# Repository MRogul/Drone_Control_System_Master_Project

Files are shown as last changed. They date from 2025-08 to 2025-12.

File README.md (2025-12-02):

# 🚀 Drone Control System – Master Project

**Test stand for evaluating drone control systems with 4DOF**  
_Master’s Thesis Project by [Michał Rogulski](https://github.com/MRogul)_

---

## 📘 Project Summary

This repository contains the full implementation of a 4-DOF quadrotor control system, including:

• custom-built experimental test stand,

• STM32 firmware for sensor acquisition, control algorithms and motor mixing,

• ESP8266-based web interface for real-time tuning,

• MATLAB/Simulink models used for controller prototyping and simulation,

• a complete validation pipeline comparing the mathematical model with real measurements.

The project was developed as part of a Master’s Thesis in Control Engineering.
---

## 📸 Real Test Stand

| Final Stand | Initial Concept |
|:---:|:---:|
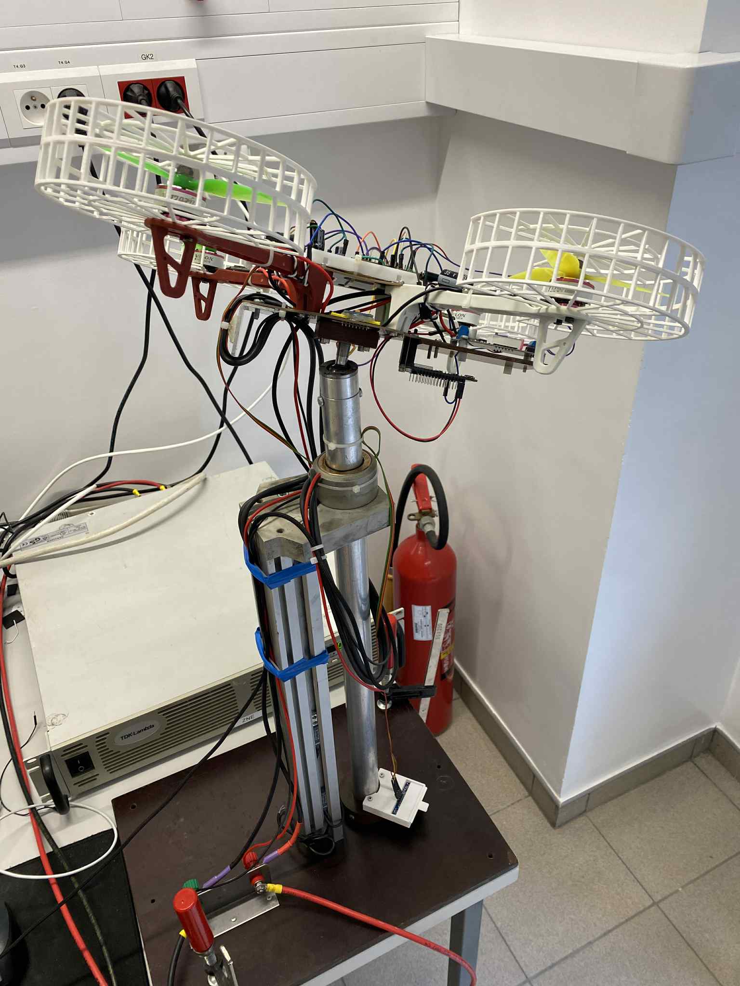
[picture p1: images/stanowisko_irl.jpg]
4DOF Stand
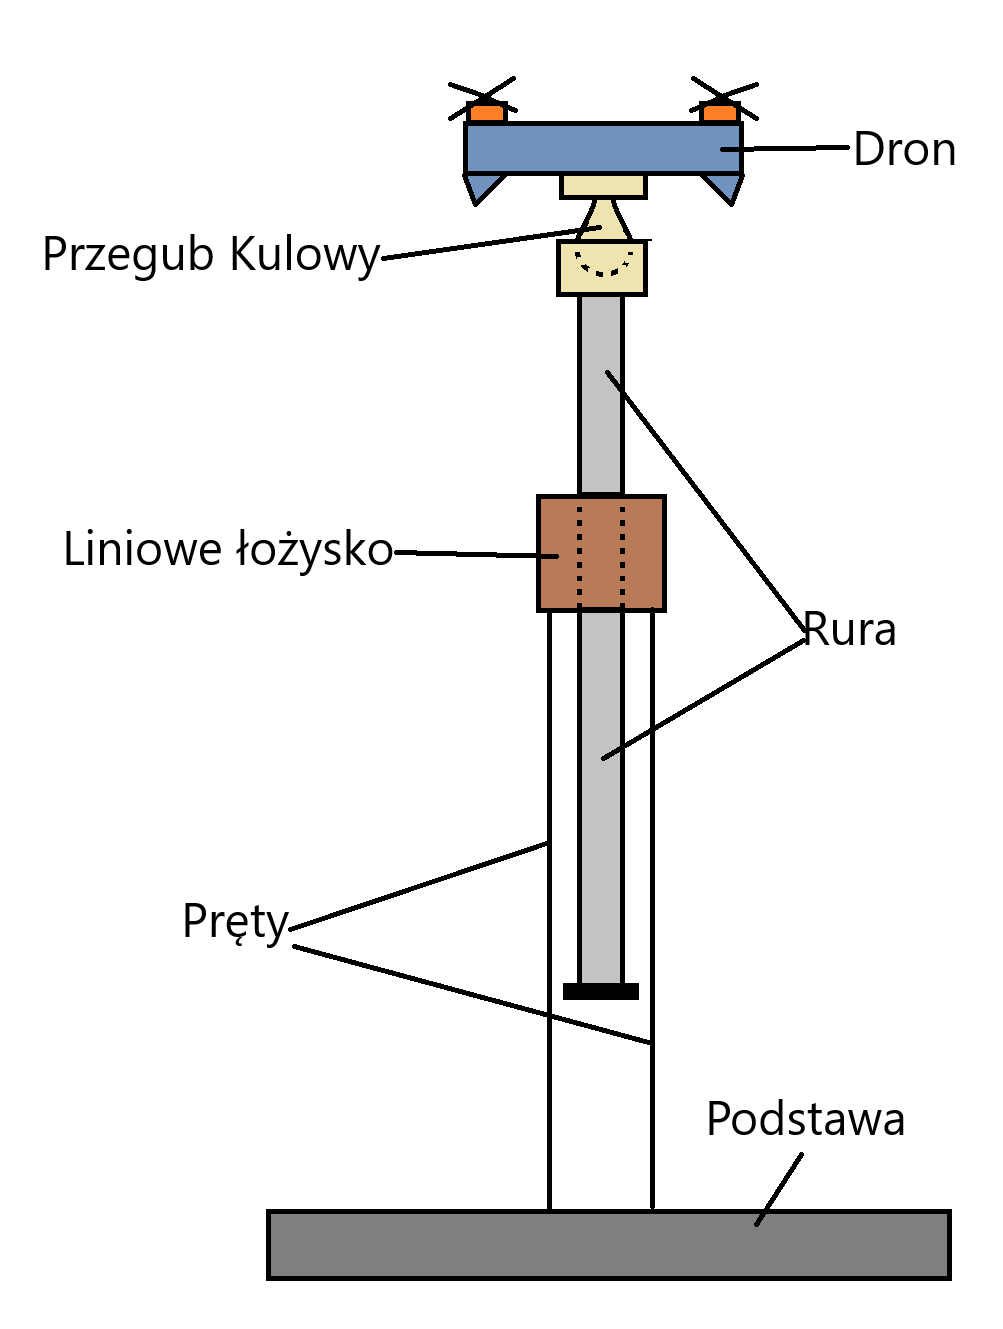
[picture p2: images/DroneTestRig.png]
Concept
|  |  |
| **4DOF Research Stand (Final version)** | **Initial design of the test rig** |

---

## ⚙️ Project Highlights

✨ **Embedded Control System (STM32)**

• Four PID loops: roll, pitch, yaw, altitude (Z)

• Derivative-on-measurement (reduces derivative kick)

• Anti-windup (conditional integration)

• Mixer for quadcopter X-configuration

• Digital ESC control via DShot300

🧠 **Sensor Fusion Algorithms**

• Complementary filter (custom implementation)

• Kalman filter (custom implementation)

• BNO055 onboard fusion (BSX) as reference

🌐 **Real-Time Tuning via ESP8266**

• Web UI hosted directly on ESP8266 (AP mode)

• Live PID tuning

• Real-time telemetry

• No need to reflash STM32 to change parameters

🛠️ **Simulation & Validation**

• 4DOF Simulink model (Plant + Sensors + Mixer + PID)

• Comparison against real test stand

• Step-response evaluation for all controlled axes

• Analysis of estimator influence on closed-loop behaviour

---

## 🗂 Repository Structure

Drone_Control_System_Master_Project/

│

├── Drone_Control/          # STM32 code (IMU, sonar, PID, mixer, DShot)

├── ESP8266/                # Web interface for real-time tuning

├── MATLAB/                 # 4DOF simulation model

├── CAD files/              # CAD files of the test stand

├── Library/BNO055/         # BNO055 Library

├── images/                 # Photos and diagrams

├── Datasheets/             # Helpful materials

├── Results/                # Responses and comparisons

└── README.md

---

## 🧠 Technologies Used

| Category | Tools |
|---|---|
| Microcontroller | STM32L432KC |
| IDE | STM32CubeMX |
| Communication | ESP8266 (Wi-Fi, Web Interface) |
| Simulation | MATLAB / Simulink |
| Visualization | STM32CubeMonitor |
| Mechanical Design | Fusion 360 / Bambu Studio |

---

## 🧪 Experimental Results

Tests performed on the 4DOF stand include:

• step responses for roll, pitch, yaw and vertical altitude (Z)

• comparison of Complementary, Kalman and BNO055 fusion

• PID tuning experiments in simulation and on hardware

• validation of control structure and estimator performance

All implemented algorithms (PID + sensor fusion) behave correctly and consistently across simulation and physical testing.

---

## 🪶 About the Project

This platform demonstrates how a complete UAV stabilization system can be built using accessible components, providing:

• safe indoor flight testing,

• repeatable laboratory experiments,

• a foundation for research on estimation & control,

• a practical educational tool for UAV control engineering.

---

## 📄 License

This project is licensed under the **MIT License**.  
You are free to use and modify it for academic or research purposes.

---

**Author:** [Michał Rogulski](https://github.com/MRogul)  
🎓 Warsaw University of Technology  
📘 [Drone_Control_System_Master_Project](https://github.com/MRogul/Drone_Control_System_Master_Project)

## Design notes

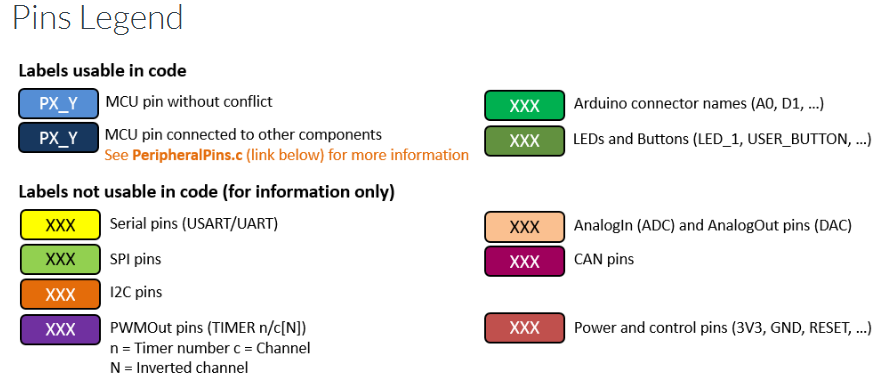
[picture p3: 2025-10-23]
Datasheets/STM32/Pinout-legend.png

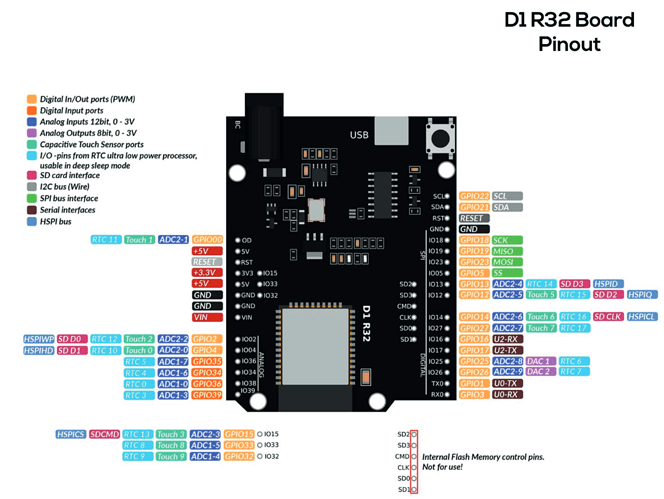
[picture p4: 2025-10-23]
Datasheets/D1 esp32 Pinout.png

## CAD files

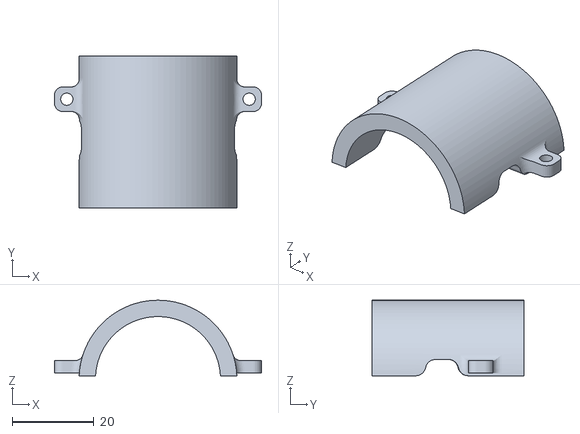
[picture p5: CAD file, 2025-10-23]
CAD files/1DOF do Drone 2 part.stl
50.5 x 37.0 x 18.4

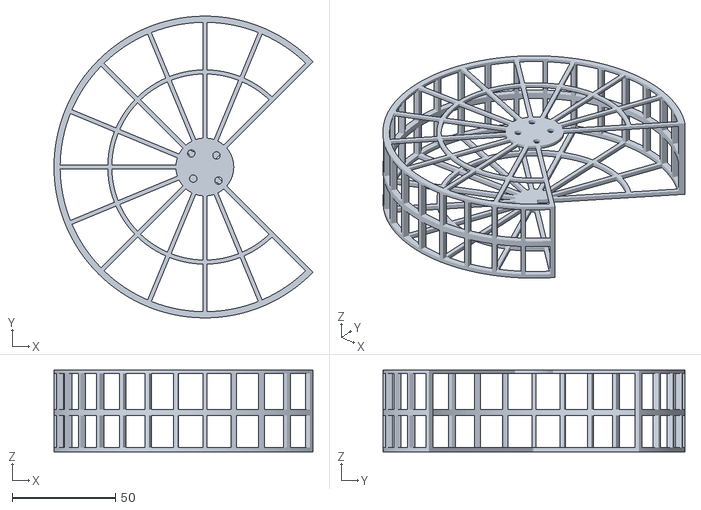
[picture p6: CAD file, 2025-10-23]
CAD files/MotorCase.stl
125.3 x 146.0 x 39.5

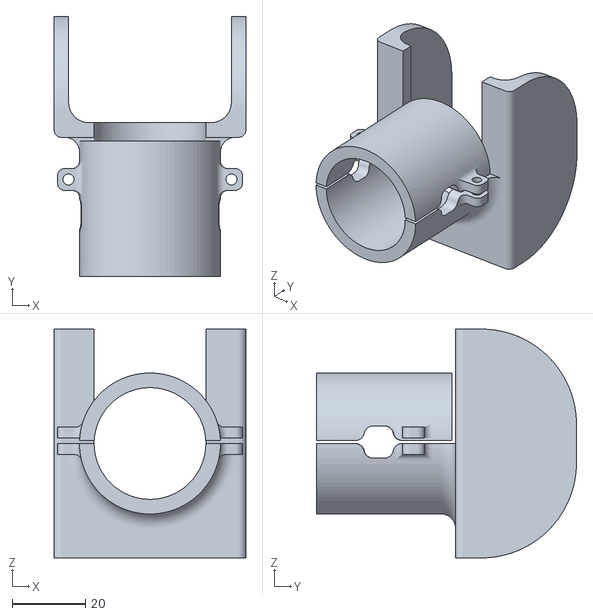
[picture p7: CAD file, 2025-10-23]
CAD files/1DOF to Drone.stl
52.4 x 71.0 x 62.5

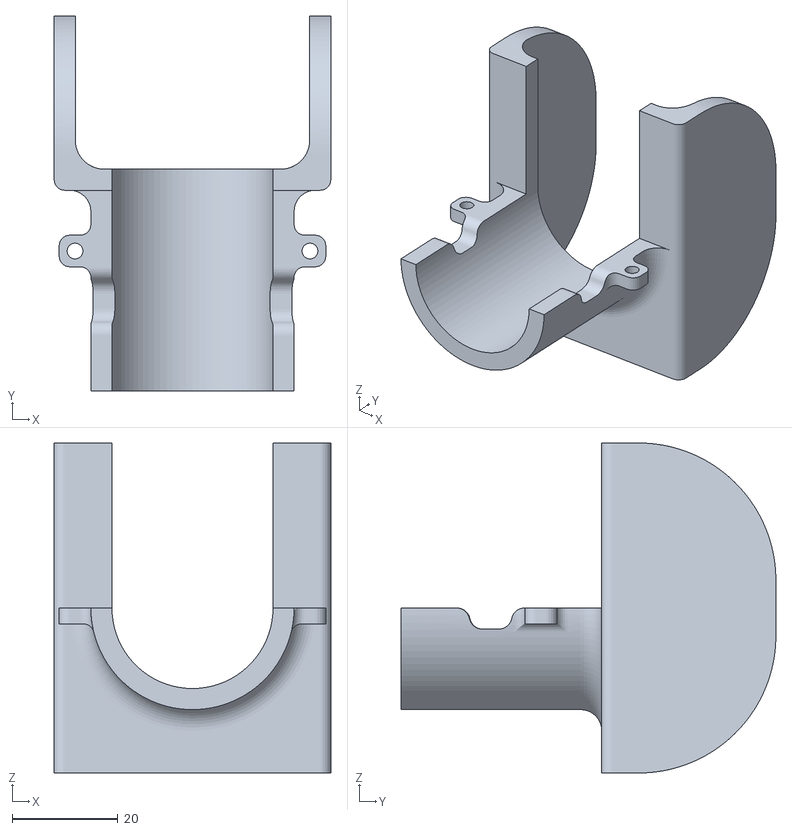
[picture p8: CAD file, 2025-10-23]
CAD files/1DOF do Drone 1part.stl
52.4 x 71.0 x 62.5

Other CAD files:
CAD files/1DOF do Drone 1part.f3d
CAD files/1DOF do Drone 2part.f3d
CAD files/1DOF do Drone.f3d
CAD files/MotorCase.f3d

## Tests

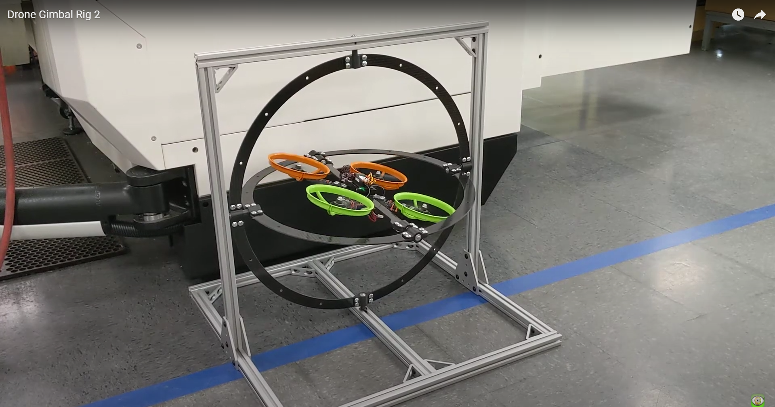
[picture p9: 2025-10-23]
images/Test rigs/3DOF-MINDS.png

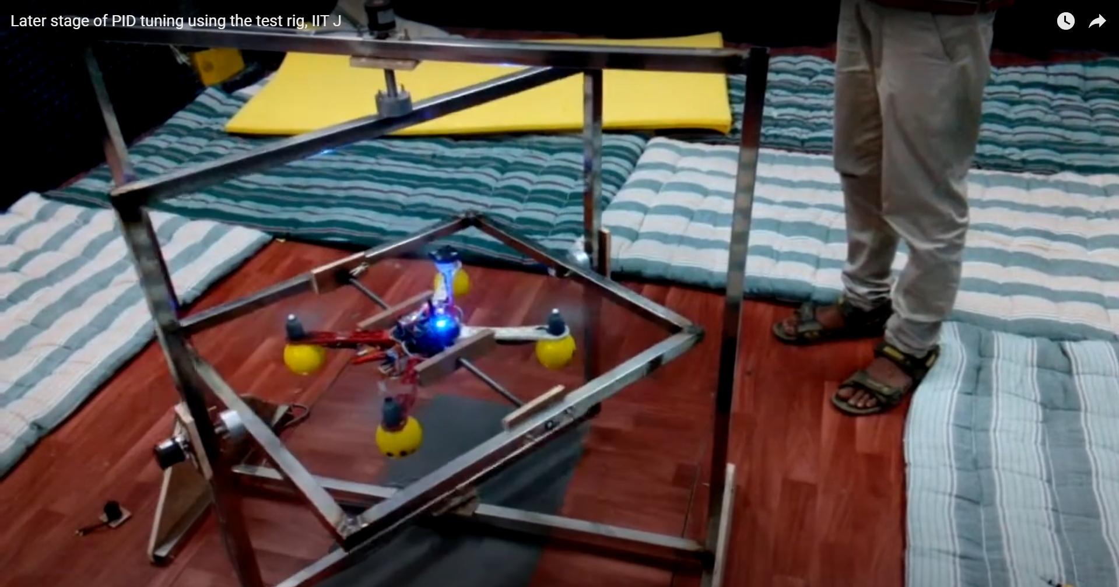
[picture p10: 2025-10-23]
images/Test rigs/3DOF-Durge.png

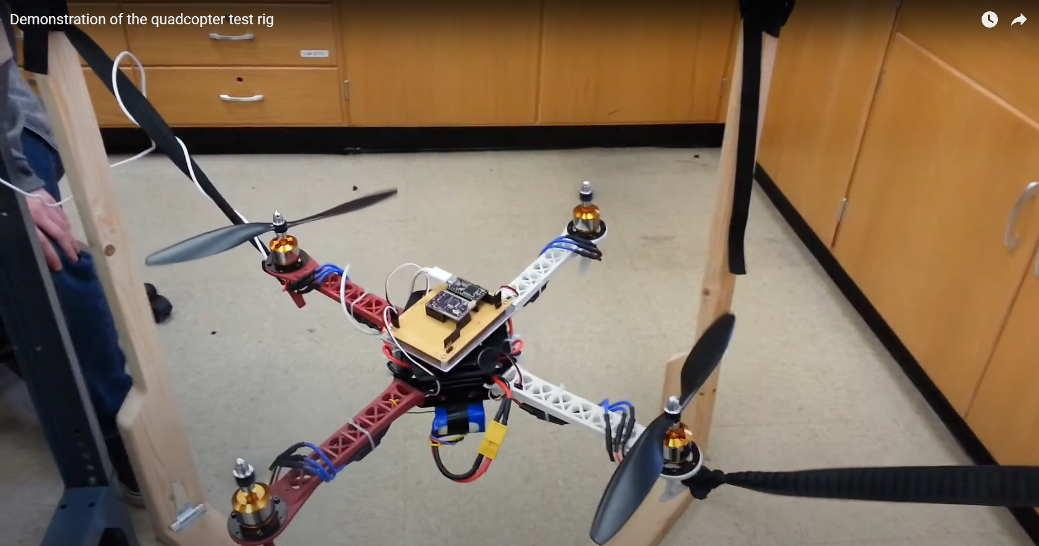
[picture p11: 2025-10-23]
images/Test rigs/DoaUAV - 1dof.png

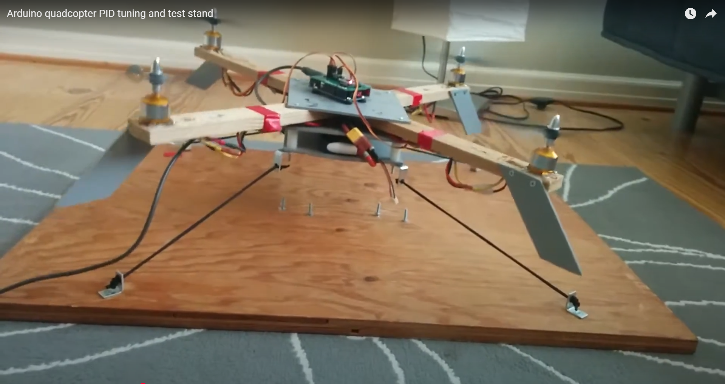
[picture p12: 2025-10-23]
images/Test rigs/2DOF-Amir.png

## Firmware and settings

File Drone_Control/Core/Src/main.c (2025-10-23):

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
/* Includes ------------------------------------------------------------------*/
#include <imu_complementary_filter.h>
#include "main.h"
#include "crc.h"
#include "dma.h"
#include "i2c.h"
#include "tim.h"
#include "usart.h"
#include "gpio.h"

/* USER CODE BEGIN Includes */
#include "dshot300.h"
#include "mpu6050.h"
#include "stdio.h"//printf function
#include "pid_controller.h"
#include <string.h>
#include <stdbool.h>
#include "bno055_stm32.h"
#include "imu_kalman_filter.h"
#include "imu_complementary_filter.h"
#include "esp32_cmd.h"
#include "hcsr04.h"

/* USER CODE END Includes */

/* USER CODE BEGIN PD */
#define ESP32_UART_HANDLE &huart2
#define ESP32_MSG_LENGTH 6
#define BNO_I2C_HANDLE &hi2c3

#define SAMPLE_TIME 0.01f

#define PID_KP_MIN 4.0f
#define PID_KP_MAX 12.0f
#define PID_KI_MIN 0.1f
#define PID_KI_MAX 5.0f
#define PID_KD_MIN 4.0f
#define PID_KD_MAX 20.0f
#define PID_TAU_MIN 0.1f
#define PID_TAU_MAX 0.2f

#define ROLL_REF_MIN -15.0f
#define ROLL_REF_MAX 15.0f

#define PITCH_REF_MIN -15.0f
#define PITCH_REF_MAX 15.0f

#define YAW_REF_MIN 100.0f
#define YAW_REF_MAX 200.0f

#define Z_REF_MIN 3.0f
#define Z_REF_MAX 20.0f

#define YAW_BIAS 150.0f

#define SPEED_MIN 48
#define MAX_SPEED 1900

#define SPEED_OFFSET 600.0f
#define ADC_TIMEOUT 1   // us

#define speed 200

//Kalman filter parameters

#define Qa_roll  0.006955685f
#define Qa_pitch  0.012531481f

#define Qb_roll  0.00006955685f
#define Qb_pitch  0.00006955685f

#define R_roll 0.00708008f
#define R_pitch 0.005146486f

/* USER CODE END PD */


/* USER CODE BEGIN PV */

/* Podstawowe dane i parametry */
uint16_t speed_ref[DSHOT_NUM_MOTORS] = {speed, speed, speed, speed};
volatile uint8_t white_button_flag = 0;

/* PID controllery */
PID_t pid_pitch;
PID_t pid_roll;
PID_t pid_yaw;
PID_t pid_z;

/* Wzmocnienia regulatorów */
float kp = 4.5f;
float ki = 2.6f;
float kd = 14.0f;
float tau = 0.09f;

float kp_y = 5.0f;
float ki_y = 1.5f;
float kd_y = 12.0f;
float tau_y = 0.1f;

float kp_z = 22.0f;
float ki_z = 6.0f;
float kd_z = 8.0f;
float tau_z = 0.1f;

/* Liczniki i sygnały odniesienia */
volatile float pid_z_counter = 1.0f;
volatile float ref_signal_counter = -1000.0f;
volatile uint8_t num_ref = 0;
volatile uint8_t num_ref_prev = 0;

/* Wartości zadane */
float REF_PITCH_ANGLE = 0.0f;
float REF_ROLL_ANGLE  = 0.0f;
float REF_YAW_ANGLE   = 100.0f;
float REF_Z_DISTANCE  = 10.0f;

/* Sekwencje sygnałów odniesienia */
static const float ref_signals[][4] = {
    // pitch, roll, yaw, z
    [0]  = {0.0, 0.0, 100.0, 10.0},
    [1]  = {0.0, 0.0, 100.0, 20.0},
    [2]  = {0.0, 0.0, 100.0, 10.0},
    [3]  = {0.0, 0.0, 200.0, 10.0},
    [4]  = {0.0, 0.0, 100.0, 10.0},
    [5]  = {10.0, 0.0, 100.0, 10.0},
    [6]  = {-10.0, 0.0, 100.0, 10.0},
    [7]  = {0.0, 10.0, 100.0, 10.0},
    [8]  = {0.0, -10.0, 100.0, 10.0},
    [9]  = {0.0, 0.0, 100.0, 10.0},
    [10] = {0.0, 0.0, 100.0, 3.0},
    [11] = {0.0, 0.0, 100.0, 10.0},
};

/* Flagi i stany systemowe */
volatile uint8_t SS = 0;
volatile uint8_t emergency_stop_flag = 0;

/* Dane z czujników i filtru */
volatile bno055_vector_t bno_vector;
volatile float copter_pitch_angle;
volatile float copter_roll_angle;
volatile float copter_yaw_angle;
volatile float copter_z_distance;

volatile float copter_pitch_angle_kal;
volatile float copter_roll_angle_kal;

/* Wyjścia regulatorów */
volatile float speed_pitch_ref;
volatile float speed_roll_ref;
volatile float speed_yaw_ref;
volatile float speed_z_ref;

/* Sygnały prędkości dla ESC */
volatile uint16_t speed_1_ref;
volatile uint16_t speed_2_ref;
volatile uint16_t speed_3_ref;
volatile uint16_t speed_4_ref;

/* Komunikacja z ESP32 */
uint8_t esp32_data_received_flag = 0;
uint8_t rx_esp32_data[ESP32_MSG_LENGTH];

/* Debug UART */
uint8_t uart_line[64];
int uart_line_length;
uint32_t UartDebugSoftTimer;

/* IMU i filtry */
MPU6050_t MPU6050;
IMU_Angles imu_angles;
KalmanFilter Roll;
KalmanFilter Pitch;

/* HC-SR04 – struktura drivera */
static HCSR04_t hcsr;

/* USER CODE END PV */


void SystemClock_Config(void);
/* USER CODE BEGIN PFP */
uint8_t compute_crc8(const uint8_t *data, uint8_t length);
/* USER CODE END PFP */

/* USER CODE BEGIN 0 */
float AngX, AngY;
/* USER CODE END 0 */

/**
  * @brief  The application entry point.
  * @retval int
  */
int main(void)
{

  /* MCU Configuration--------------------------------------------------------*/

  /* Reset of all peripherals, Initializes the Flash interface and the Systick. */
  HAL_Init();

  /* Configure the system clock */
  SystemClock_Config();

  /* Initialize all configured peripherals */
  MX_GPIO_Init();
  MX_DMA_Init();
  MX_USART2_UART_Init();
  MX_CRC_Init();
  MX_I2C3_Init();
  MX_TIM1_Init();
  MX_USART1_UART_Init();
  MX_TIM2_Init();
  MX_TIM15_Init();
  /* USER CODE BEGIN 2 */
  //MPU6050_Init(&hi2c3);
  //MPU6050_Calibrate_Gyro(&hi2c3, &MPU6050, 500);

  Kalman_Init(&Roll, Qa_roll, Qb_roll, R_roll);
  Kalman_Init(&Pitch, Qa_pitch, Qb_pitch, R_pitch);

  HAL_TIM_Base_Start(&htim2); //Czas do czujników odległościowych
  HAL_TIM_Base_Start_IT(&htim15); //Timer od częstotliwości regulatora i wysyłania prędkości do drona
  //HAL_TIM_Base_Start_IT(&htim1); // control loop interrupt


  // PID controllers
  	PID_Init_Bartek_s_Lab(&pid_pitch, kp, ki, kd,
  	tau, -250.0f, 250.0f, SAMPLE_TIME);

  	PID_Init_Bartek_s_Lab(&pid_roll, kp, ki, kd,
  	tau, -250.0f, 250.0f, SAMPLE_TIME);

  	PID_Init_Bartek_s_Lab(&pid_yaw, kp_y, ki_y, kd_y,
  	tau_y, -300.0f, 300.0f, SAMPLE_TIME);

  	PID_Init_Bartek_s_Lab(&pid_z, kp_z, ki_z, kd_z,
  	  	tau_z, -150.0f, 400.0f, SAMPLE_TIME);

  	UartDebugSoftTimer = HAL_GetTick();

	HAL_Delay(2000); // let the motor stop after uC RST

	dshot_arm_all_esc();

//	SS=2;

	// AHRS
		bno055_assignI2C(BNO_I2C_HANDLE);
		bno055_setup();
		bno055_setOperationModeNDOF();

	static ESP32_CmdCtx esp_ctx = {
		    .pid_pitch = &pid_pitch,
		    .pid_roll  = &pid_roll,
		    .pid_yaw   = &pid_yaw,
		    .pid_z     = &pid_z,

		    .kp = &kp, .ki = &ki, .kd = &kd, .tau = &tau,

		    .kp_y = &kp_y, .ki_y = &ki_y, .kd_y = &kd_y, .tau_y = &tau_y,
		    .kp_z = &kp_z, .ki_z = &ki_z, .kd_z = &kd_z, .tau_z = &tau_z,

		    .ref_roll  = &REF_ROLL_ANGLE,
		    .ref_pitch = &REF_PITCH_ANGLE,
		    .ref_yaw   = &REF_YAW_ANGLE,
		    .ref_z     = &REF_Z_DISTANCE,

		    .kp_min = PID_KP_MIN,   .kp_max = PID_KP_MAX,
		    .ki_min = PID_KI_MIN,   .ki_max = PID_KI_MAX,
		    .kd_min = PID_KD_MIN,   .kd_max = PID_KD_MAX,
		    .tau_min = PID_TAU_MIN, .tau_max = PID_TAU_MAX,

		    .roll_min  = ROLL_REF_MIN,   .roll_max  = ROLL_REF_MAX,
		    .pitch_min = PITCH_REF_MIN,  .pitch_max = PITCH_REF_MAX,
		    .yaw_min   = YAW_REF_MIN,    .yaw_max   = YAW_REF_MAX,
		    .z_min     = Z_REF_MIN,      .z_max     = Z_REF_MAX,
		};

	/* HC-SR04: TIM2 jako licznik czasu ECHO, TRIG/ECHO jak w CubeMX */
	HCSR04_Init(&hcsr,
	            &htim2,
	            1000000u,                  /* timer_hz (tu 1 MHz) */
	            TRIG_PIN_GPIO_Port, TRIG_PIN_Pin,
	            ECHO_PIN_Pin);

	/* Opcjonalnie: co 6 wywołań timera sterującego zrób trigger (jak Twój Trig_counter) */
	HCSR04_SetPeriodicDivider(&hcsr, 6);
	/* Opcjonalnie: długość impulsu TRIG (domyślnie ~50 µs) */
	HCSR04_SetTrigPulse(&hcsr, 400);


  /* USER CODE END 2 */

  /* Infinite loop */
  /* USER CODE BEGIN WHILE */

  	memset(rx_esp32_data, 0x00, ESP32_MSG_LENGTH); //Zeruje bufor rx_esp32_data
  	HAL_UART_Receive_IT(ESP32_UART_HANDLE, rx_esp32_data,ESP32_MSG_LENGTH); // uruchamia odbieranie danych przez UART w trybie przerwań. Kiedy dane przyjdą, zostanie wywołane HAL_UART_RxCpltCallback.
	while (1)
	{

		if (white_button_flag == 1)
		{
			white_button_flag = 0;
			__NOP();
		}
	    (void)ESP32_PollAndProcess(&esp32_data_received_flag,
	                               rx_esp32_data,
	                               ESP32_MSG_LENGTH,    // = 6
	                               &esp_ctx);



//		PID_Controller_Update_Gains(&pid_pitch, kp, ki, kd, tau);
//		PID_Controller_Update_Gains(&pid_roll, kp, ki, kd, tau);
//		PID_Controller_Update_Gains(&pid_yaw, kp_y, ki_y, kd_y, tau_y);
//		PID_Controller_Update_Gains(&pid_z, kp_z, ki_z, kd_z, tau_z);
		if (num_ref!=num_ref_prev){
			REF_SIGNAL(num_ref);
			num_ref_prev=num_ref;
		}

    /* USER CODE END WHILE */

    /* USER CODE BEGIN 3 */
	}
  /* USER CODE END 3 */
}

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
/* USER CODE BEGIN 4 */

//////////////////FUNKCJA ODPOWIADAJĄCA ZA PRZELICZENIE WYCHYLENIA NA PRĘDKOŚCI REFERENCYJNE SILNIKÓW/////////////////////////

void HAL_TIM_PeriodElapsedCallback(TIM_HandleTypeDef *htim) //wejście w przerwanie
{
	uint16_t speeds[4];
	uint16_t base[4];
	//float U_vec[3];

	if (htim->Instance == TIM15) //sprawdzenie od którego timera jest przerwanie
	{
		/* Periodyczne wyzwalanie pomiaru odległości */
		(void)HCSR04_OnPeriodic(&hcsr);

		/* Jeśli przyszła nowa próbka – pobierz i przypisz do zmiennej systemowej */
		if (HCSR04_HasNew(&hcsr)) {
		    copter_z_distance = HCSR04_GetDistanceCm(&hcsr);
		}


		/*
		/////////////POBIERANIE WYCHYLENIA Z CZUJNIKA MPU6050/////////////
		MPU6050_Read_All(&hi2c3, &MPU6050);
		copter_pitch_angle = MPU6050.KalmanAngleX;
		copter_roll_angle = MPU6050.KalmanAngleY;
		copter_yaw_angle+=MPU6050.Gz*SAMPLE_TIME;
		*/
		//////////////DANE Z BNO(SUROWE+WEWNĘTRZNA FUZJA)//////////
		bno055_vector_t acc= bno055_getVectorAccelerometer();

//		ac_x=acc.x;
//	    ac_x  = atan2f(acc.y, acc.z) * 57.2958;
//	    ac_x_f= 0.7f*acc.x+0.3f*ac_x_f;
//	    ac_y=acc.y;
//	    ac_y = atan2f(-acc.x, sqrtf(acc.y*acc.y + acc.z*acc.z)) * 57.2958;
//	    ac_y_f= 0.7f*acc.y+0.3f*ac_y_f;
		bno055_vector_t gyro= bno055_getVectorGyroscope();
//		gyr_x=0.8f*gyro.x+0.2f*gyr_x;
//		gyr_y=0.8f*gyro.y+0.2f*gyr_y;;
//		IMU_Fusion_Update(&imu_angles, acc.x, acc.y, acc.z, gyro.x, gyro.y, gyro.z, SAMPLE_TIME);
//
//		copter_pitch_angle_komp = -imu_angles.pitch;
//		copter_roll_angle_komp = -imu_angles.roll;

		Kalman_Update(&copter_roll_angle_kal, &copter_pitch_angle_kal, &Roll, &Pitch, acc.x, acc.y, acc.z, gyro.x, gyro.y, gyro.z);

		////////////////DANE Z BNO(ZEWNĘTRZNA FUZJA)///////////////////


		bno_vector = bno055_getVectorEuler();
		copter_pitch_angle = copter_pitch_angle_kal;
		copter_roll_angle = copter_roll_angle_kal;

//		copter_pitch_angle = bno_vector.y;
//		copter_roll_angle = bno_vector.z;
		copter_yaw_angle = bno_vector.x;

		//////////////////OBLICZANIE WYJŚCIA REGULATORA WYKORZYSTUJĄC ERROR ORAZ REF ANGLE//////////////////
		if(SS==1){
			speed_pitch_ref = PID_Controller_Bartek_s_Lab(&pid_pitch,REF_PITCH_ANGLE,
					copter_pitch_angle);
			speed_roll_ref = PID_Controller_Bartek_s_Lab(&pid_roll, REF_ROLL_ANGLE,
					copter_roll_angle);
			speed_yaw_ref = PID_Controller_Bartek_s_Lab(&pid_yaw, REF_YAW_ANGLE,
					copter_yaw_angle);


			////////////////3DOF/////////////////////

			if(pid_z_counter!=0){
				speed_1_ref = (uint16_t) (SPEED_OFFSET + speed_roll_ref
						+ speed_pitch_ref +speed_yaw_ref);
				speed_2_ref = (uint16_t) (SPEED_OFFSET + speed_roll_ref
						- speed_pitch_ref -speed_yaw_ref);
				speed_3_ref = (uint16_t) (SPEED_OFFSET - speed_roll_ref
						- speed_pitch_ref +speed_yaw_ref);
				speed_4_ref = (uint16_t) (SPEED_OFFSET - speed_roll_ref
						+ speed_pitch_ref -speed_yaw_ref);
			}
//
//
//
//			////////////////4DOF/////////////////////
			else {
				speed_z_ref = PID_Controller_Bartek_s_Lab(&pid_z, REF_Z_DISTANCE,
										copter_z_distance);

//				speed_1_ref = (uint16_t) (SPEED_OFFSET + speed_roll_ref
//						+ speed_pitch_ref +speed_yaw_ref+speed_z_ref);
//				speed_2_ref = (uint16_t) (SPEED_OFFSET + speed_roll_ref
//						- speed_pitch_ref -speed_yaw_ref+speed_z_ref);
//				speed_3_ref = (uint16_t) (SPEED_OFFSET - speed_roll_ref
//						- speed_pitch_ref +speed_yaw_ref+speed_z_ref);
//				speed_4_ref = (uint16_t) (SPEED_OFFSET - speed_roll_ref
//						+ speed_pitch_ref -speed_yaw_ref+speed_z_ref);

				speed_1_ref = (uint16_t) (SPEED_OFFSET + speed_roll_ref
						+ speed_pitch_ref +speed_yaw_ref);
				speed_2_ref = (uint16_t) (SPEED_OFFSET + speed_roll_ref
						- speed_pitch_ref -speed_yaw_ref);
				speed_3_ref = (uint16_t) (SPEED_OFFSET - speed_roll_ref
						- speed_pitch_ref +speed_yaw_ref);
				speed_4_ref = (uint16_t) (SPEED_OFFSET - speed_roll_ref
						+ speed_pitch_ref -speed_yaw_ref);
			}

//
			if (ref_signal_counter==500){
				num_ref++;
				ref_signal_counter=0;
			}

			////////////////2DOF/////////////////////

//			speed_1_ref = (uint16_t) (SPEED_OFFSET + speed_roll_ref
//					+ speed_pitch_ref);
//			speed_2_ref = (uint16_t) (SPEED_OFFSET + speed_roll_ref
//					- speed_pitch_ref);
//			speed_3_ref = (uint16_t) (SPEED_OFFSET - speed_roll_ref
//					- speed_pitch_ref);
//			speed_4_ref = (uint16_t) (SPEED_OFFSET - speed_roll_ref
//					+ speed_pitch_ref);


			/////////////1DOF///////////////////////////

//			speed_1_ref = (uint16_t) (SPEED_OFFSET + speed_roll_ref);
//			speed_2_ref = (uint16_t) (SPEED_OFFSET + speed_roll_ref);
//			speed_3_ref = (uint16_t) (SPEED_OFFSET - speed_roll_ref);
//			speed_4_ref = (uint16_t) (SPEED_OFFSET - speed_roll_ref);

			///////////////SPRAWDZENIE CZY PRĘDKOŚCI MIESZCZĄ SIĘ W ZAKRESIE//////////
			// Double-check :))
			if (speed_1_ref < 48)
			{
				speed_1_ref = 48;
			}
			else if (speed_1_ref > MAX_SPEED)
			{
				speed_1_ref = MAX_SPEED;
			}
			else
			{
				__NOP();
			}

			if (speed_2_ref < 48)
			{
				speed_2_ref = 48;
			}
			else if (speed_2_ref > MAX_SPEED)
			{
				speed_2_ref = MAX_SPEED;
			}
			else
			{
				__NOP();
			}

			if (speed_3_ref < 48)
			{
				speed_3_ref = 48;
			}
			else if (speed_3_ref > MAX_SPEED)
			{
				speed_3_ref = MAX_SPEED;
			}
			else
			{
				__NOP();
			}

			if (speed_4_ref < 48)
			{
				speed_4_ref = 48;
			}
			else if (speed_4_ref > MAX_SPEED)
			{
				speed_4_ref = MAX_SPEED;
			}
			else
			{
				__NOP();
			}
			/////////WYSYŁANIE PRĘDKOŚCI DO ESC////////////
			speeds[0] = speed_1_ref;
			speeds[1] = speed_2_ref;
			speeds[2] = speed_3_ref;
			speeds[3] = speed_4_ref;
			dshot_send_all_ref_speeds(speeds);
//			base[0]=speed_test;
//			base[1]=speed_test;
//			base[2]=speed_test;
//			base[3]=speed_test;
//			dshot_send_all_ref_speeds(base);
			ref_signal_counter++;
			if(pid_z_counter<700 && pid_z_counter!=0)
			{
				pid_z_counter++;
			}
			else{
				pid_z_counter=0;
			}

		}



		else if (SS==2){
			__NOP();
		}


		else{
			base[0]=speed;
			base[1]=speed;
			base[2]=speed;
			base[3]=speed;
			dshot_send_all_ref_speeds(base);
		}

	}
}

void HAL_UART_RxCpltCallback(UART_HandleTypeDef *huart)
{
	if (huart->Instance == USART2)
	{
		esp32_data_received_flag = 1;
		HAL_UART_Receive_IT(huart, rx_esp32_data, ESP32_MSG_LENGTH);
	}
}

void HAL_GPIO_EXTI_Callback(uint16_t GPIO_Pin)
{
    /* Obsługa HC-SR04 (ECHO) */
    HCSR04_ProcessExti(&hcsr, GPIO_Pin);

}


void REF_SIGNAL(volatile uint8_t num) {
    if (num < sizeof(ref_signals)/sizeof(ref_signals[0])) {
        if (num == 11) {
            SS = 0;
        } else {
            REF_PITCH_ANGLE = ref_signals[num][0];
            REF_ROLL_ANGLE = ref_signals[num][1];
            REF_YAW_ANGLE = ref_signals[num][2];
            REF_Z_DISTANCE = ref_signals[num][3];
        }
    } else {
        num_ref = 12;
        num_ref_prev = 12;
    }
}
/* USER CODE END 4 */
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


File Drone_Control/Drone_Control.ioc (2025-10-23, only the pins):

Mcu.UserName=STM32L432KCUx
PA0.GPIO_Label=MCO [High speed clock in]
PA0.Signal=RCC_CK_IN
PA10.Signal=S_TIM1_CH3
PA11.Signal=S_TIM1_CH4
PA2.Signal=USART2_TX
PA3.Signal=USART2_RX
PA5.GPIO_Label=TRIG_PIN
PA5.Signal=GPIO_Output
PA7.Signal=I2C3_SCL
PA8.Signal=S_TIM1_CH1
PA9.Signal=S_TIM1_CH2
PB0.GPIO_Label=ECHO_PIN
PB0.Signal=GPXTI0
PB6.Signal=USART1_TX
PB7.Signal=USART1_RX

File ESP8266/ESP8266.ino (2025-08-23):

#include <Arduino.h>
#include <ESP8266WiFi.h>
#include <ESPAsyncTCP.h>
#include <ESPAsyncWebServer.h>
#include <LittleFS.h>
#include <Arduino_JSON.h>

#define STM32_SERIAL Serial

AsyncWebServer server(80);
AsyncWebSocket ws("/ws");

uint8_t uart_msg[6];
String message = "";
String sliderValue1 = "0";
String sliderValue2 = "0";
String sliderValue3 = "0";
String sliderValue4 = "0";
String sliderValue5 = "0";
String sliderValue6 = "0";
String sliderValue7 = "0";
String sliderValue8 = "0";


int kp_percentage;
int ki_percentage;
int kd_percentage;
int tau_percentage;
int roll_ref_percentage;
int pitch_ref_percentage;
int yaw_ref_percentage;
int z_ref_percentage;

const char* ssid = "ESP8266-Access-Point";
const char* password = "123456789";

JSONVar sliderValues;

String getSliderValues() {
  sliderValues["sliderValue1"] = sliderValue1;
  sliderValues["sliderValue2"] = sliderValue2;
  sliderValues["sliderValue3"] = sliderValue3;
  sliderValues["sliderValue4"] = sliderValue4;
  sliderValues["sliderValue5"] = sliderValue5;
  sliderValues["sliderValue6"] = sliderValue6;
  sliderValues["sliderValue7"] = sliderValue7;
  sliderValues["sliderValue8"] = sliderValue8;
  return JSON.stringify(sliderValues);
}

uint8_t crc8(uint8_t *data, uint8_t data_length) {
  uint8_t crc = 0xFF;
  uint8_t poly = 0x1D;
  while (data_length--) {
    crc ^= *data++;
    for (int i = 0; i < 8; i++) {
      crc = crc & 0x80 ? (crc << 1) ^ poly : crc << 1;
    }
  }
  return crc;
}

void initFS() {
  if (!LittleFS.begin()) {
    //Serial.println("Error mounting LittleFS");
  } else {
    //Serial.println("LittleFS mounted");
  }
}

void initWiFi() {
  WiFi.mode(WIFI_AP);
  WiFi.softAP(ssid, password);
  //Serial.print("AP IP: ");
  //Serial.println(WiFi.softAPIP());
}

void notifyClients(String sliderValues) {
  ws.textAll(sliderValues);
}

void handleWebSocketMessage(void *arg, uint8_t *data, size_t len) {
  static unsigned long lastSendTime = 0;
  const unsigned long throttleInterval = 50;
  
  if (millis() - lastSendTime < throttleInterval) return;
  lastSendTime = millis();

  AwsFrameInfo *info = (AwsFrameInfo*)arg;
  if (info->final && info->index == 0 && info->len == len && info->opcode == WS_TEXT) {
    data[len] = 0;
    message = (char*)data;
    
    if (message.indexOf("1s") >= 0 || message.indexOf("2s") >= 0 || 
        message.indexOf("3s") >= 0 || message.indexOf("4s") >= 0 ||
        message.indexOf("5s") >= 0 || message.indexOf("6s") >= 0 || 
        message.indexOf("7s") >= 0 || message.indexOf("8s") >= 0) {
      
      if (message.indexOf("1s") >= 0) {
        sliderValue1 = message.substring(2);
        kp_percentage = sliderValue1.toInt();
        uart_msg[0] = 0x01;
        memcpy(uart_msg + 1, (char*)&kp_percentage, 4);
      } 
      else if (message.indexOf("2s") >= 0) {
        sliderValue2 = message.substring(2);
        ki_percentage = sliderValue2.toInt();
        uart_msg[0] = 0x02;
        memcpy(uart_msg + 1, (char*)&ki_percentage, 4);
      }
      else if (message.indexOf("3s") >= 0) {
        sliderValue3 = message.substring(2);
        kd_percentage = sliderValue3.toInt();
        uart_msg[0] = 0x03;
        memcpy(uart_msg + 1, (char*)&kd_percentage, 4);
      }
      else if (message.indexOf("4s") >= 0) {
        sliderValue4 = message.substring(2);
        tau_percentage = sliderValue4.toInt();
        uart_msg[0] = 0x04;
        memcpy(uart_msg + 1, (char*)&tau_percentage, 4);
      }
      else if (message.indexOf("5s") >= 0) {
        sliderValue5 = message.substring(2);
        roll_ref_percentage = sliderValue5.toInt();
        uart_msg[0] = 0x05;
        memcpy(uart_msg + 1, (char*)&roll_ref_percentage, 4);
      }
      else if (message.indexOf("6s") >= 0) {
        sliderValue6 = message.substring(2);
        pitch_ref_percentage = sliderValue6.toInt();
        uart_msg[0] = 0x06;
        memcpy(uart_msg + 1, (char*)&pitch_ref_percentage, 4);
      }
      else if (message.indexOf("7s") >= 0) {
        sliderValue7 = message.substring(2);
        yaw_ref_percentage = sliderValue7.toInt();
        uart_msg[0] = 0x07;
        memcpy(uart_msg + 1, (char*)&yaw_ref_percentage, 4);
      }
      else if (message.indexOf("8s") >= 0) {
        sliderValue8 = message.substring(2);
        z_ref_percentage = sliderValue8.toInt();
        uart_msg[0] = 0x08;
        memcpy(uart_msg + 1, (char*)&z_ref_percentage, 4);
      }

      uart_msg[5] = crc8(uart_msg, 5);
      
      while (STM32_SERIAL.availableForWrite() < 6) delay(1);
      STM32_SERIAL.write(uart_msg, 6);
      STM32_SERIAL.flush();
      
      //Serial.println(getSliderValues());
      notifyClients(getSliderValues());
    }
    else if (strcmp((char*)data, "getValues") == 0) {
      notifyClients(getSliderValues());
    }
  }
}

void onEvent(AsyncWebSocket *server, AsyncWebSocketClient *client, AwsEventType type,
             void *arg, uint8_t *data, size_t len) {
  switch (type) {
    case WS_EVT_CONNECT:
      //Serial.printf("Client #%u connected\n", client->id());
      break;
    case WS_EVT_DISCONNECT:
      //Serial.printf("Client #%u disconnected\n", client->id());
      break;
    case WS_EVT_DATA:
      handleWebSocketMessage(arg, data, len);
      break;
    default: break;
  }
}

void initWebSocket() {
  ws.onEvent(onEvent);
  server.addHandler(&ws);
}

void setup() {
  STM32_SERIAL.begin(57600);

  initFS();
  initWiFi();
  initWebSocket();

  server.on("/", HTTP_GET, [](AsyncWebServerRequest *request) {
    request->send(LittleFS, "/index.html", "text/html");
  });
  server.serveStatic("/", LittleFS, "/");
  server.begin();
}

void loop() {
  ws.cleanupClients();
}

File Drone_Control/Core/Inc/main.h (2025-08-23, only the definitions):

#define MCO_Pin GPIO_PIN_0
#define MCO_GPIO_Port GPIOA
#define TRIG_PIN_Pin GPIO_PIN_5
#define TRIG_PIN_GPIO_Port GPIOA
#define ECHO_PIN_Pin GPIO_PIN_0
#define ECHO_PIN_GPIO_Port GPIOB
#define ECHO_PIN_EXTI_IRQn EXTI0_IRQn
#define SWDIO_Pin GPIO_PIN_13
#define SWDIO_GPIO_Port GPIOA
#define SWCLK_Pin GPIO_PIN_14
#define SWCLK_GPIO_Port GPIOA
#define LD3_Pin GPIO_PIN_3
#define LD3_GPIO_Port GPIOB

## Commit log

2025-06-23 First commit. In this commit there is 2DOF PID regulator, rotation matrix(not implemented in regulation yet), ultrasound sensor configuration, Dshot, ESP32 configuration with data handle.
2025-06-24 Yaw and ESP32
    Adding yaw angle (its drifting) + adding EPS32 folder with web server in
    [Drone_Control Debug.cfg]
2025-06-24 Yaw and EPS32
2025-06-25 Gyro offset and ultrasound sensor
2025-06-25 basic flow for cubeMonitor
2025-07-01 AP mode in ESP32 (still in progress), BNO055 implemented, HCSR04 corrected
    [Drone_Control.ioc, main.c, mpu6050.c]
2025-07-01 Building new library for calculating throttle, ready 2DOF regulator with good initial parameters. Testing 1DOF regulator
2025-07-01 2DOF regulator, arm library and creating new library for throttle calculation
    [ARMCA5neon_config.txt, ARMCA7neon_config.txt, ARMCA9neon_config.txt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]
2025-07-15 3DOF regulator, canceled new library for throttle.
2025-07-15 4DOF (still in progress- need new motor cases)
2025-07-24 Complementary filter (without transfering to euler angles) and changed regulator structure (BNO055 diff orientation)
2025-08-11 Kalman filter
2025-08-13 fixed kalman and complementary. 4DOF regulation
    [dshot150.c, main.c]
2025-08-18 esp32->esp8266 Uart communication and web serwer
2025-08-19 Sensor fusion test and esp8266 communication finished
    [Log_myVariablesDrone_2025-08-19_15h49m29s.csv, Log_myVariablesDrone_2025-08-19_15h57m21s.csv, Log_myVariablesDrone_2025-08-19_15h59m40s.csv]
2025-08-20 Finished- low pass filter for both kalman and complementary filter
    [Log_myVariablesDrone_2025-08-13_12h35m44s.csv, Log_myVariablesDrone_2025-08-13_12h35m58s.csv, Log_myVariablesDrone_2025-08-13_12h37m39s.csv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]
2025-09-18 R and Q update in Kalman Filter
2025-09-22 Gyro bias, gryo noise and acc noise
2025-09-25 new Kalman filter collected data and maltlab files with FFT funnction
    [Log_myVariablesDrone_2025-09-25_12h48m00s.csv, Log_myVariablesDrone_2025-09-25_14h23m42s.csv, Log_myVariablesDrone_2025-09-25_14h29m09s.csv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]
2025-10-24 Remove local data folders from repository and add to .gitignore
    [Log_myVariablesDrone_2025-08-13_12h37m39s.csv, Log_myVariablesDrone_2025-08-13_16h47m24s.csv, Log_myVariablesDrone_2025-08-13_17h58m21s.csv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]

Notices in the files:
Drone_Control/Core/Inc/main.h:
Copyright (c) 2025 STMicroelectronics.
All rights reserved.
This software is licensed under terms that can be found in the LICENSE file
